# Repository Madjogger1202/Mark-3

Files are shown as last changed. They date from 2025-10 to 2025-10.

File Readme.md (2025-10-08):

# Mark 3 — Robot Dog Control Board

> High-current RP2350B-based controller board for quadruped robots.  
> Integrated **battery protection**, **PD charging**, **per-leg power domains**, and **radio/IMU** subsystem.  
> Designed for compact 4-legged robots with modular legs and high servo load.

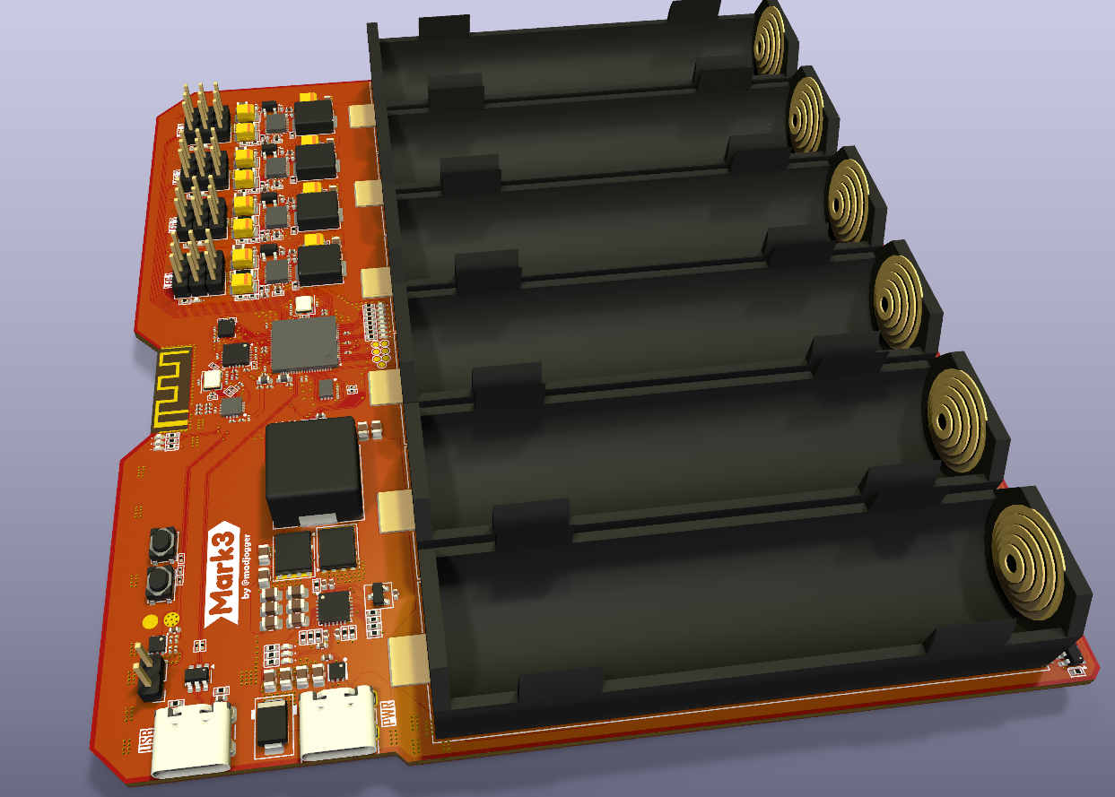
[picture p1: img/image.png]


---

## What’s on the board
- **Main MCU:** RP2350B (USB-programmable)
- **Power system:**
  - **6 × 18650** cells in **parallel** (on-board holders)
  - **Protection IC:** DW01 for undervoltage / overcurrent safety  
  - **USB Type-C PD** charging via **HUSB237-AA001-DN06R** (default 15 V profile, configurable)
  - **Battery charger:** BQ24610, up to **10 A charge current**
  - **Four TPS61088** boost converters — each provides **6 V / 10 A** per leg
  - Individual **enable lines** for each leg’s converter
  - **Current-sense** circuit per leg power rail
- **IMU:** LSM6DS3 (SPI interface)
- **Radio:** nRF24L01P (integrated 2.4 GHz transceiver)
- **LED indication:**
  - 8 × battery-level LEDs
  - 2 × status LEDs (power / charging / fault)
- **Two separate USB-C ports:**
  - **Programming** (direct to RP2350B)
  - **Charging** (PD trigger + BQ24610)
- **BOOT** button for UF2 flashing  
- All power and signal routing optimized for servo current spikes

---

## Power System Overview
| Function | Component | Voltage | Current | Notes |
|:--|:--|:--|:--|:--|
| PD Trigger | HUSB237-AA001-DN06R | 15 V (default) | up to 3 A | Configurable by resistors |
| Charger | BQ24610 | 15 V → Battery | up to 10 A | 1S6P Li-ion |
| Protection | DW01 | 1S | — | Undervoltage / overcurrent cutoff |
| Boost × 4 | TPS61088 | 6 V | 10 A each | One per leg |
| MCU & Logic | RP2350B + LDO | 3.3 V | — | Isolated domain |

> ⚠️ **Do not** connect external 5 V to the MCU port while PD charging.  
> Power and data paths are separate to prevent back-feed.

---

## Sensors & Interfaces
- **LSM6DS3 (SPI)** — motion sensing (accelerometer + gyroscope)  
- **nRF24L01P (SPI)** — wireless communication  
- Expansion headers for extra sensors (I²C / SPI / UART)  
- Servo outputs grouped per leg (3 per leg × 4 legs)

---

## Battery Section
- 6 × **18650 cells in parallel**
- **DW01** provides basic protection (no balancing)
- On-board holders for easy replacement
- **LED bar (8 segments)** for charge level indication

---
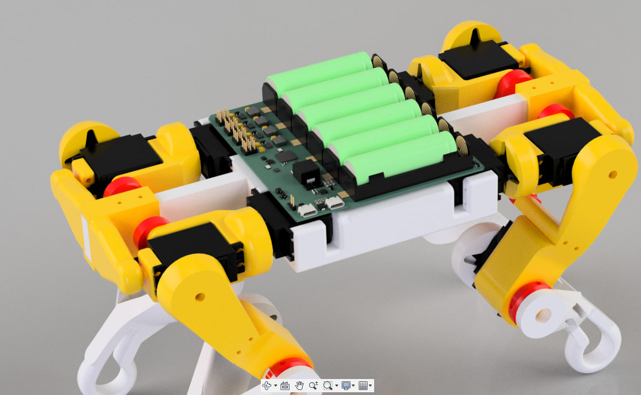
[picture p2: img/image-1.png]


## Quick Use
1. Insert 6× 18650 cells into holders.  
2. Connect USB-C **charging** port (PD trigger negotiates 15 V).  
3. Wait for charge LEDs to show full battery.  
4. Connect USB-C **programming** port to PC.  
5. Hold **BOOT** and power the board to enter UF2 mode.  
6. Flash firmware to RP2350B.  
7. Control each leg’s power domain and read current measurements as needed.

---

## Typical Applications
- Quadruped robots (up to 4 legs, 3 servos per leg)
- High-current servo testing rigs
- Portable motion control platforms
- Development base for RP2350 motion control firmware

---

## Notes
- Each leg’s 6 V converter (TPS61088) can be disabled via GPIO.  
- Charging and MCU USB ports are independent.  
- PD trigger default = 15 V (can be changed by resistor network).  
- Full pinout and schematics in `/docs/Mark3_schematic.pdf`.

---

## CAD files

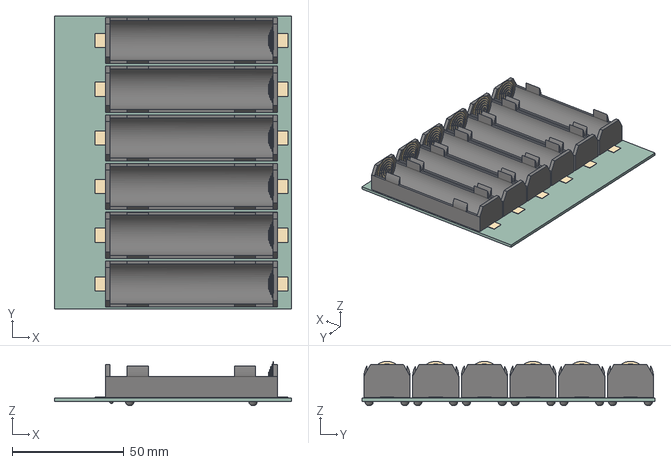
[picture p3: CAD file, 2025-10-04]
Mark-3.step
106.2 x 131.2 x 19.8 mm
BatteryHolder_Keystone_1042_1x18650 x 6
Mark-3_PCB

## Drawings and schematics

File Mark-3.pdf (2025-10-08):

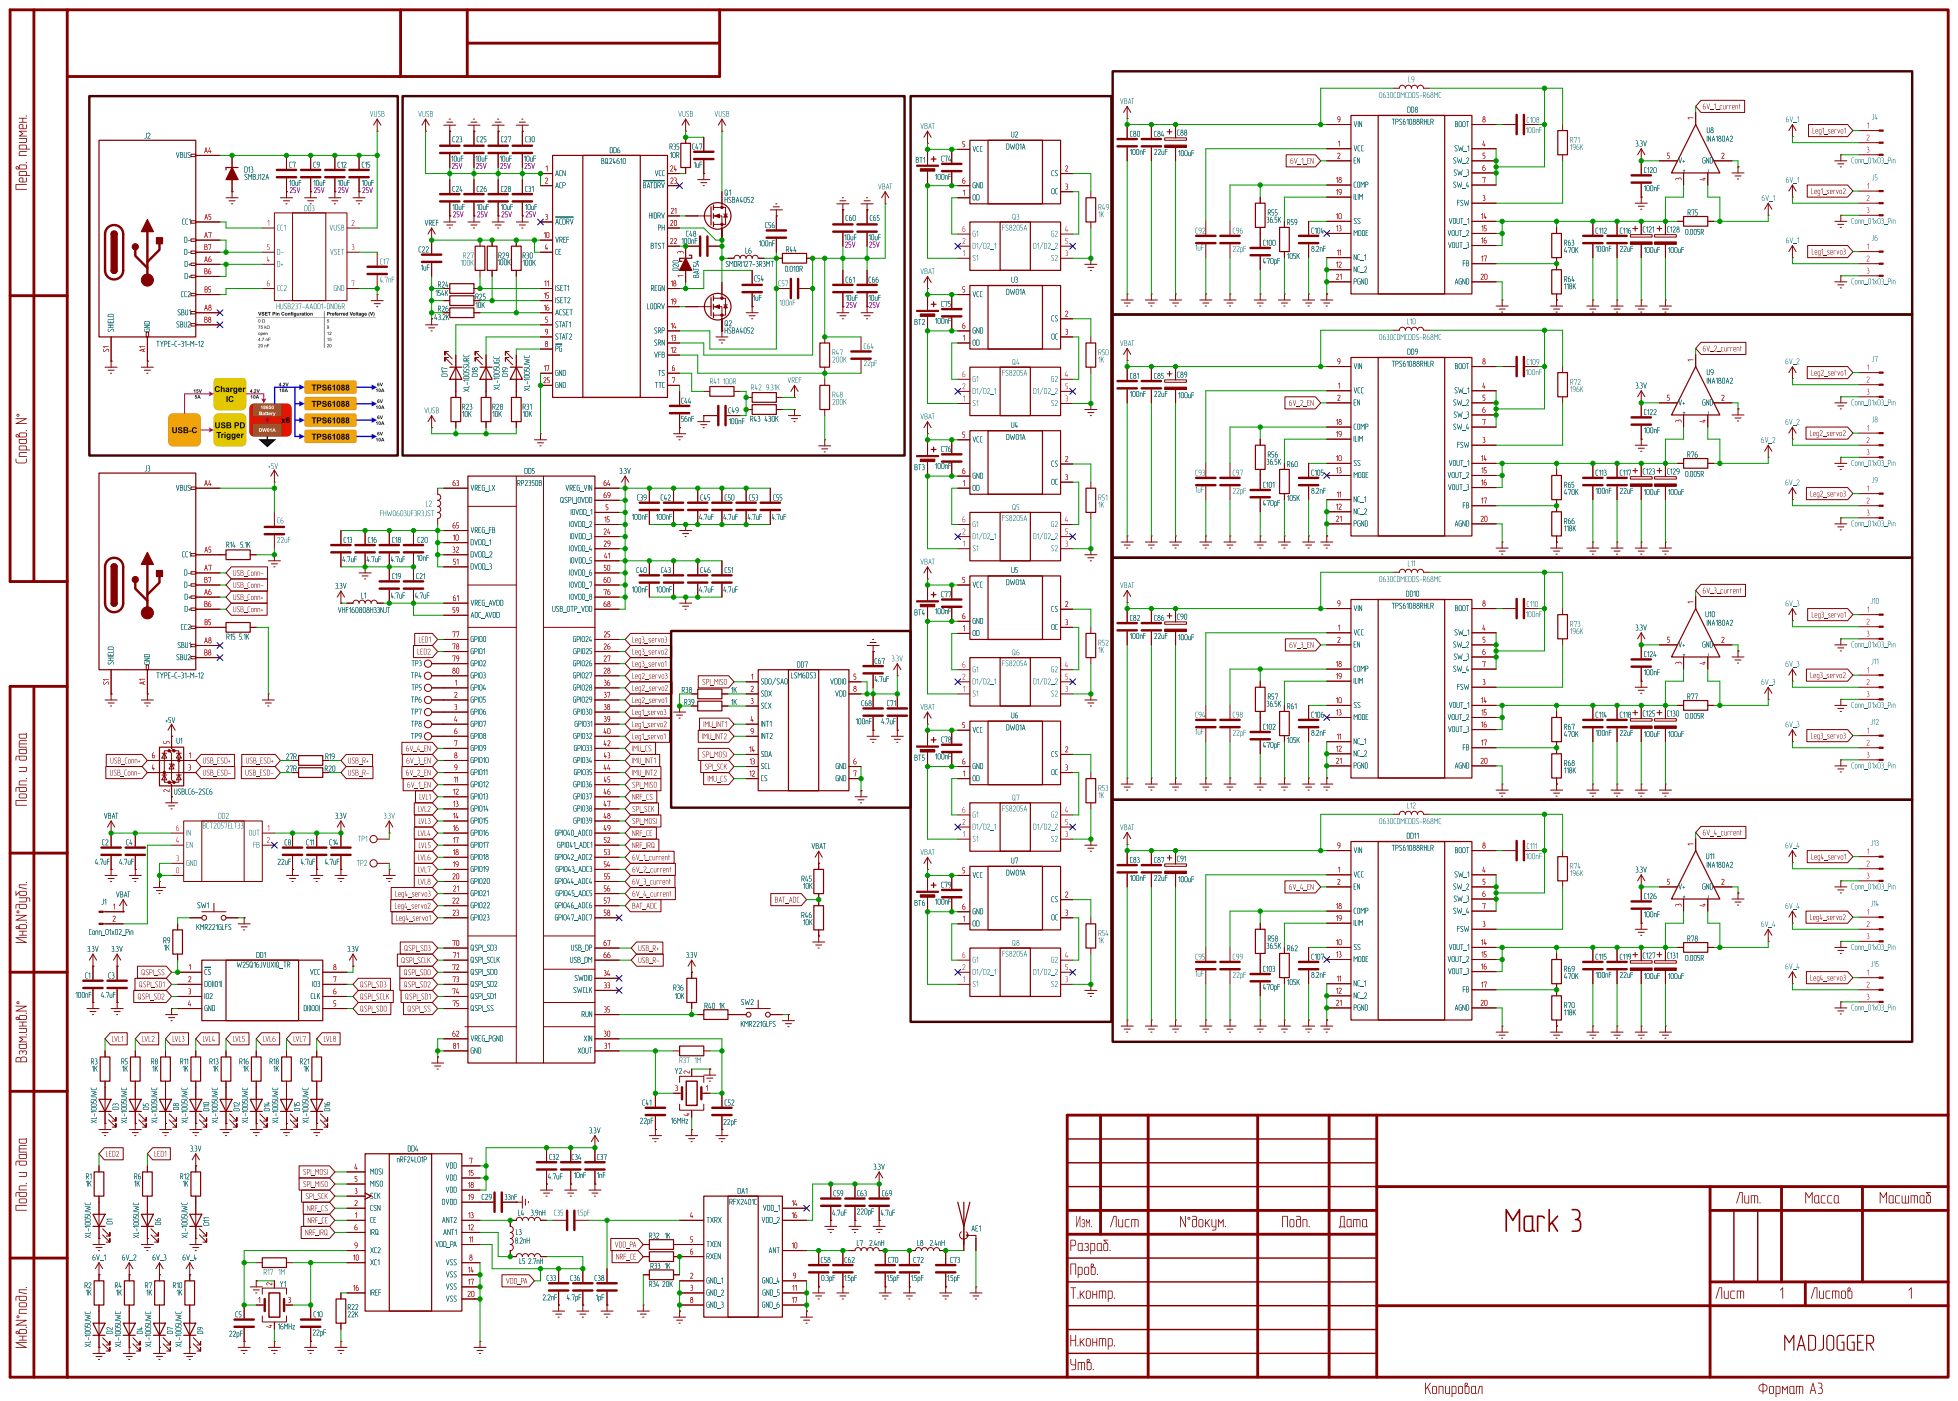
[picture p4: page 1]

VIN 9 VCC 1 EN 2 COMP 18

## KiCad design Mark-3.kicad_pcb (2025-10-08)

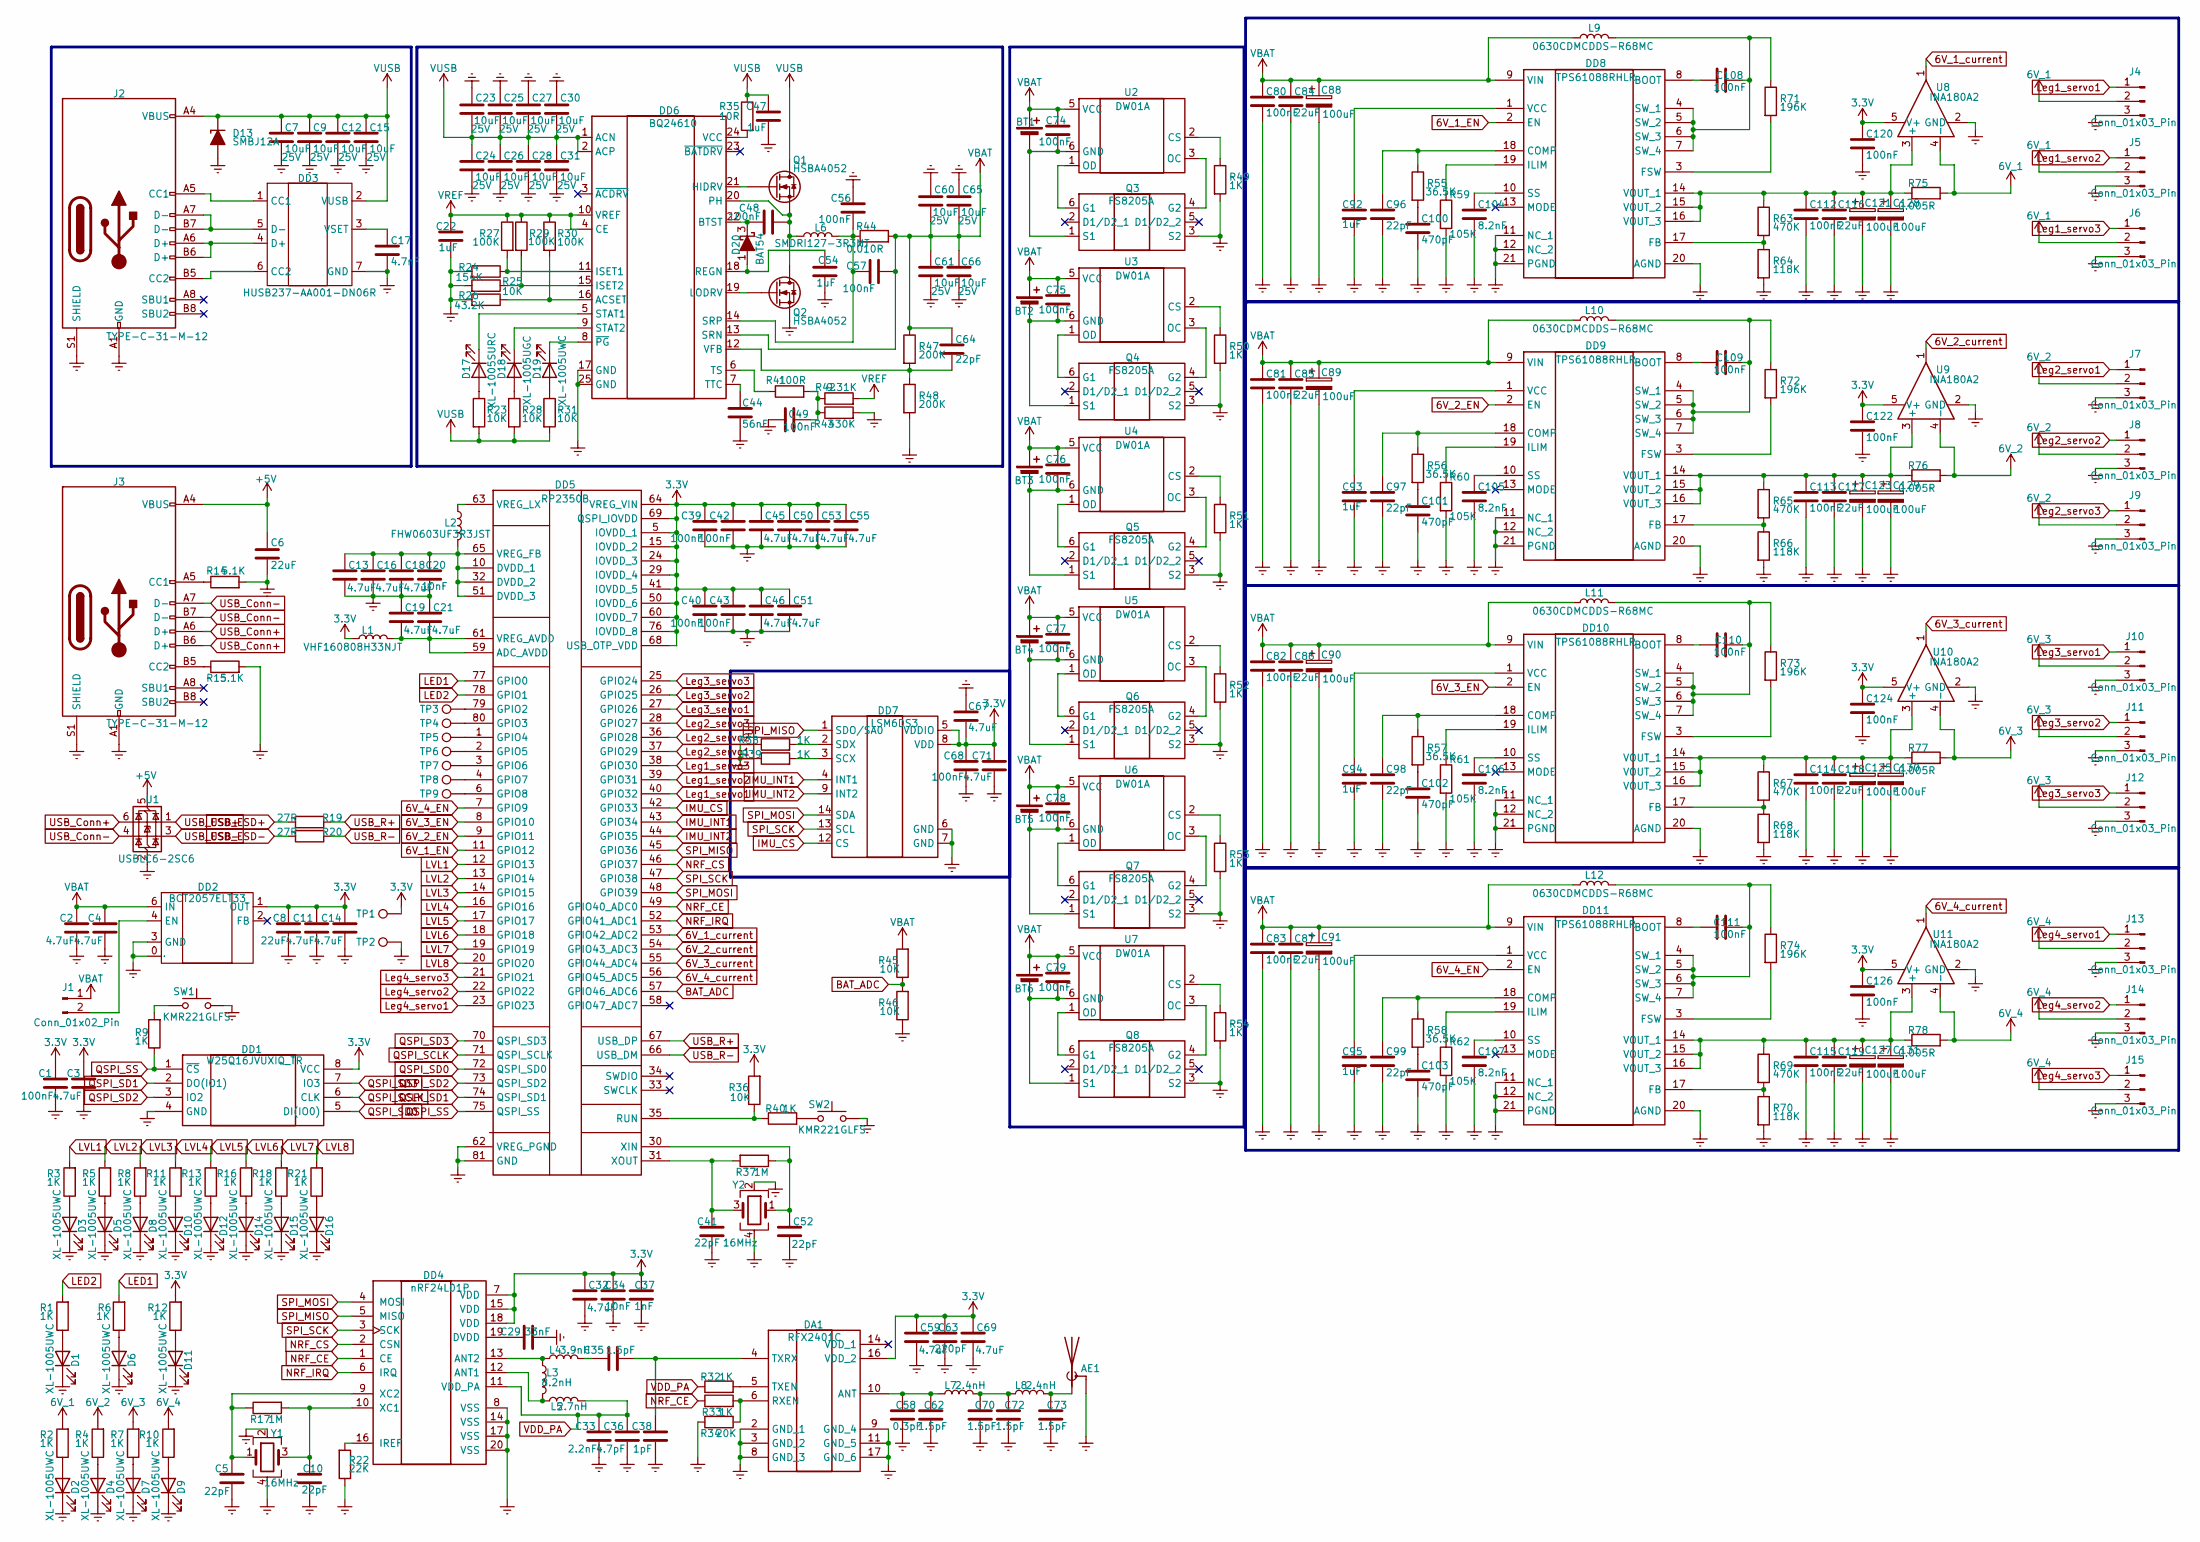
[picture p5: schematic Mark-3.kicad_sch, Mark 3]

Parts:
AE1: Antenna_Shield; Texas_SWRA117D_2.4GHz_Right
BT1, BT2, BT3, BT4, BT5, BT6: Battery_Cell; BatteryHolder_Keystone_1042_1x18650
C1, C39, C40, C42, C43, C68: 100nF; C_0201_0603Metric
C2, C3, C4, C11, C13, C14, C16, C18, C19, C21, C32, C45, C46, C50, C51, C53, C55, C59, C67, C69, C71: 4.7uF; C_0201_0603Metric
C5, C10, C41, C52: 22pF; C_0201_0603Metric
C6, C8: 22uF; C_0402_1005Metric
C7, C9, C12, C15, C23, C24, C25, C26, C27, C28, C30, C31, C60, C61, C65, C66: 10uF; C_0805_2012Metric; Voltage 25V; JLCPCB part C5674
C17: 4.7nF; C_0402_1005Metric; JLCPCB part C5674
C20, C34: 10nF; C_0201_0603Metric
C22, C47, C54, C92, C93, C94, C95: 1uF; C_0402_1005Metric; JLCPCB part C5674
C29: 33nF; C_0201_0603Metric
C33: 2.2nF; C_0201_0603Metric
C35, C62, C70, C72, C73: 1.5pF; C_0201_0603Metric
C36: 4.7pF; C_0201_0603Metric
C37: 1nF; C_0201_0603Metric
C38: 1pF; C_0201_0603Metric
C44: 56nF; C_0402_1005Metric; JLCPCB part C5674
C48, C49, C56, C57, C74, C75, C76, C77, C78, C79, C80, C81, C82, C83, C108, C109, C110, C111, C112, C113, C114, C115, C120, C122, C124, C126: 100nF; C_0402_1005Metric; JLCPCB part C5674
C58: 0.3pF; C_0201_0603Metric
C63: 220pF; C_0201_0603Metric
C64, C96, C97, C98, C99: 22pF; C_0402_1005Metric; JLCPCB part C5674
C84, C85, C86, C87, C116, C117, C118, C119: 22uF; C_0805_2012Metric; JLCPCB part C5674
C88, C89, C90, C91, C121, C123, C125, C127, C128, C129, C130, C131: 100uF; CP_EIA-3528-21_Kemet-B; JLCPCB part C140381
C100, C101, C102, C103: 470pF; C_0402_1005Metric; JLCPCB part C5674
C104, C105, C106, C107: 8.2nF; C_0402_1005Metric; JLCPCB part C5674
D1, D2, D3, D4, D5, D6, D7, D8, D9, D10, D11, D12, D14, D15, D16, D19: XL-1005UWC; LED_0402_1005Metric
D13: SMBJ12A; D_SMB
D17: XL-1005SURC; LED_0402_1005Metric
D18: XL-1005UGC; LED_0402_1005Metric
D20: BAT54; SOT-23
DA1: RFX2401C; Manufacturer_Part_Number RFX2401C; Mouser Part Number 477-RFX2401C
DD1: W25Q16JVUXIQ_TR; W25Q16JVUXIQ; Manufacturer_Part_Number W25Q16JVUXIQ TR; Mouser Part Number 454-W25Q16JVUXIQTR
DD2: BCT2057ELT33; BCT2057ELTAJ; Manufacturer Part BCT2057ELTAJ-TR; LCSC Part Name 1A, 低 dropout 线性稳压器
DD3: HUSB237-AA001-DN06R; Manufacturer Part HUSB237-AA001-DN06R; LCSC Part Name HUSB237-AA001-DN06R
DD4: nRF24L01P; QFN-20-1EP_4x4mm_P0.5mm_EP2.5x2.5mm
DD5: RP2350B; QFN40P1000X1000X90-81N-D; Manufacturer_Part_Number RP2350B
DD6: BQ24610; VQFN-24-1EP_4x4mm_P0.5mm_EP2.45x2.45mm
DD7: LSM6DS3; LGA-14_3x2.5mm_P0.5mm_LayoutBorder3x4y
DD8, DD9, DD10, DD11: TPS61088RHLR; Manufacturer_Part_Number TPS61088RHLR; Mouser Part Number 595-TPS61088RHLR
J1: Conn_01x02_Pin; PinHeader_1x02_P2.54mm_Vertical
J2: TYPE-C-31-M-12; USB_C_Receptacle_G-Switch_GT-USB-7010ASV
J3: TYPE-C-31-M-12; USB_C_Receptacle_GCT_USB4105-xx-A_16P_TopMnt_Horizontal
J4, J5, J6, J7, J8, J9, J10, J11, J12, J13, J14, J15: Conn_01x03_Pin; PinHeader_1x03_P2.54mm_Vertical
L1: VHF160808H33NJT; L_0603_1608Metric
L2: FHW0603UF3R3JST; L_0603_1608Metric
L3: 8.2nH; L_0201_0603Metric
L4: 3.9nH; L_0201_0603Metric
L5: 2.7nH; L_0201_0603Metric
L6: SMDRI127-3R3MT; L_SXN_SMDRI127
L7, L8: 2.4nH; L_0201_0603Metric
L9, L10, L11, L12: 0630CDMCDDS-R68MC; L_Sunlord_MWSA0603S
Q1, Q2: HSBA4052; PQFN-8-EP_6x5mm_P1.27mm_Generic
Q3, Q4, Q5, Q6, Q7, Q8: FS8205A; Manufacturer_Part_Number FS8205A
R1, R2, R3, R4, R5, R6, R7, R8, R10, R11, R12, R13, R16, R18, R21, R49, R50, R51, R52, R53, R54: 1K; R_0402_1005Metric
R9, R32, R33, R38, R39, R40: 1K; R_0201_0603Metric
R14, R15: 5.1K; R_0402_1005Metric
R17, R37: 1M; R_0201_0603Metric
R19, R20: 27R; R_0201_0603Metric
R22: 22K; R_0201_0603Metric
R23, R25, R28, R31: 10K; R_0402_1005Metric
R24: 154K; R_0402_1005Metric
R26: 43.2K; R_0402_1005Metric
R27, R29, R30: 100K; R_0402_1005Metric
R34: 20K; R_0201_0603Metric
R35: 10R; R_0402_1005Metric
R36, R45, R46: 10K; R_0201_0603Metric
R41: 100R; R_0402_1005Metric
R42: 9.31K; R_0402_1005Metric
R43: 430K; R_0402_1005Metric
R44: 0.010R; R_2512_6332Metric_Pad1.40x3.35mm
R47, R48: 200K; R_0402_1005Metric
R55, R56, R57, R58: 36.5K; R_0402_1005Metric
R59, R60, R61, R62: 105K; R_0402_1005Metric
R63, R65, R67, R69: 470K; R_0402_1005Metric
R64, R66, R68, R70: 118K; R_0402_1005Metric
R71, R72, R73, R74: 196K; R_0402_1005Metric
R75, R76, R77, R78: 0.005R; R_1206_3216Metric
SW1, SW2: KMR221GLFS; SW_SPST_PTS810
TP1, TP2, TP3, TP4, TP5, TP6, TP7, TP8, TP9: TestPoint; TestPoint_Pad_D1.0mm
U1: USBLC6-2SC6; SOT-23-6
U2, U3, U4, U5, U6, U7: DW01A; SOT-23-6
U8, U9, U10, U11: INA180A2; SOT-23-5
Y1, Y2: 16MHz; Crystal_SMD_3225-4Pin_3.2x2.5mm

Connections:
3.3V: C1.1, C3.1, C8.1, C11.1, C14.1, C32.1, C34.1, C37.1, C39.1, C40.1, C42.1, C43.1, C45.1, C46.1, C50.1, C51.1, C53.1, C55.1, C59.1, C63.1, C67.1, C68.1, C69.1, C71.1, C120.1, C122.1, C124.1, C126.1, DA1.16 (VDD_2), DD1.8 (VCC), DD2.1 (OUT), DD4.7 (VDD), DD4.15 (VDD), DD4.18 (VDD), DD5.5 (IOVDD_1), DD5.15 (IOVDD_2), DD5.24 (IOVDD_3), DD5.29 (IOVDD_4), DD5.41 (IOVDD_5), DD5.50 (IOVDD_6), DD5.60 (IOVDD_7), DD5.64 (VREG_VIN), DD5.68 (USB_OTP_VDD), DD5.69 (QSPI_IOVDD), DD5.76 (IOVDD_8), DD7.5 (VDDIO), DD7.8 (VDD), L1.1, R12.2, R36.2, TP1.1, U8.5 (V+), U9.5 (V+), U10.5 (V+), U11.5 (V+)
6V_1: J4.2, J5.2, J6.2, R2.2, R75.2, U8.4 (-)
6V_1_EN: DD5.11 (GPIO12), DD8.2 (EN)
6V_1_current: DD5.53 (GPIO42_ADC2), U8.1
6V_2: J7.2, J8.2, J9.2, R4.2, R76.2, U9.4 (-)
6V_2_EN: DD5.9 (GPIO11), DD9.2 (EN)
6V_2_current: DD5.54 (GPIO43_ADC3), U9.1
6V_3: J10.2, J11.2, J12.2, R7.2, R77.2, U10.4 (-)
6V_3_EN: DD5.8 (GPIO10), DD10.2 (EN)
6V_3_current: DD5.55 (GPIO44_ADC4), U10.1
6V_4: J13.2, J14.2, J15.2, R10.2, R78.2, U11.4 (-)
6V_4_EN: DD5.7 (GPIO9), DD11.2 (EN)
6V_4_current: DD5.56 (GPIO45_ADC5), U11.1
+5V: C6.1, J3.A4 (VBUS), J3.A9 (VBUS), J3.B4 (VBUS), J3.B9 (VBUS), U1.5 (VBUS)
BAT_ADC: DD5.57 (GPIO46_ADC6), R45.1, R46.2
Earth: AE1.2 (Shield), C1.2, C2.2, C3.2, C4.2, C5.2, C6.2, C7.2, C8.2, C9.2, C10.2, C11.2, C12.2, C13.2, C14.2, C15.2, C16.2, C17.2, C18.2, C19.1, C20.2, C21.1, C22.2, C23.2, C24.2, C25.2, C26.2, C27.2, C28.2, C29.2, C30.2, C31.2, C32.2, C33.2, C34.2, C36.2, C37.2, C38.2, C39.2, C40.2, C41.2, C42.2, C43.2, C44.2, C45.2, C46.2, C47.1, C49.1, C50.2, C51.2, C52.2, C53.2, C54.1, C55.2, C56.2, C58.2, C59.2, C60.2, C61.2, C62.2, C63.2, C65.2, C66.2, C67.2, C68.2, C69.2, C70.2, C71.2, C72.2, C73.2, C80.2, C81.2, C82.2, C83.2, C84.2, C85.2, C86.2, C87.2, C88.2, C89.2, C90.2, C91.2, C92.2, C93.2, C94.2, C95.2, C96.2, C97.2, C98.2, C99.2, C100.2, C101.2, C102.2, C103.2, C104.2, C105.2, C106.2, C107.2, C112.2, C113.2, C114.2, C115.2, C116.2, C117.2, C118.2, C119.2, C120.2, C121.2, C122.2, C123.2, C124.2, C125.2, C126.2, C127.2, C128.2, C129.2, C130.2, C131.2, D1.1 (K), D2.1 (K), D3.1 (K), D4.1 (K), D5.1 (K), D6.1 (K), D7.1 (K), D8.1 (K), D9.1 (K), D10.1 (K), D11.1 (K), D12.1 (K), D13.2 (A), D14.1 (K), D15.1 (K), D16.1 (K), DA1.2 (GND_1), DA1.3 (GND_2), DA1.8 (GND_3), DA1.9 (GND_4), DA1.11 (GND_5), DA1.17 (GND_6), DD1.4 (GND), DD2.0 (EP), DD2.3 (GND), DD3.7 (GND), DD4.8 (VSS), DD4.14 (VSS), DD4.17 (VSS), DD4.20 (VSS), DD4.21 (PAD), DD5.62 (VREG_PGND), DD5.81 (GND), DD6.17 (GND), DD6.25 (GND), DD7.6 (GND), DD7.7 (GND), DD8.11 (NC_1), DD8.12 (NC_2), DD8.20 (AGND), DD8.21 (PGND), DD9.11 (NC_1), DD9.12 (NC_2), DD9.20 (AGND), DD9.21 (PGND), DD10.11 (NC_1), DD10.12 (NC_2), DD10.20 (AGND), DD10.21 (PGND), DD11.11 (NC_1), DD11.12 (NC_2), DD11.20 (AGND), DD11.21 (PGND), J2.A1 (GND), J2.A12 (GND), J2.B1 (GND), J2.B12 (GND), J2.S1 (SHIELD), J3.A1 (GND), J3.A12 (GND), J3.B1 (GND), J3.B12 (GND), J3.S1 (SHIELD), J4.3, J5.3, J6.3, J7.3, J8.3, J9.3, J10.3, J11.3, J12.3, J13.3, J14.3, J15.3, Q2.1 (S), Q2.2 (S), Q2.3 (S), Q3.3 (S2), Q4.3 (S2), Q5.3 (S2), Q6.3 (S2), Q7.3 (S2), Q8.3 (S2), R14.2, R15.2, R22.1, R24.2, R25.2, R26.2, R34.2, R38.1, R39.1, R43.2, R46.1, R48.2, R49.2, R50.2, R51.2, R52.2, R53.2, R54.2, R59.2, R60.2, R61.2, R62.2, R64.2, R66.2, R68.2, R70.2, SW1.1, SW2.1, TP2.1, U1.2 (GND), U8.2 (GND), U9.2 (GND), U10.2 (GND), U11.2 (GND), Y1.2, Y1.4, Y2.2, Y2.4
IMU_CS: DD5.42 (GPIO33), DD7.12 (CS)
IMU_INT1: DD5.43 (GPIO34), DD7.4 (INT1)
IMU_INT2: DD5.44 (GPIO35), DD7.9 (INT2)
LED1: DD5.77 (GPIO0), R6.2
LED2: DD5.78 (GPIO1), R1.2
LVL1: DD5.12 (GPIO13), R3.2
LVL2: DD5.13 (GPIO14), R5.2
LVL3: DD5.14 (GPIO15), R8.2
LVL4: DD5.16 (GPIO16), R11.2
LVL5: DD5.17 (GPIO17), R13.2
LVL6: DD5.18 (GPIO18), R16.2
LVL7: DD5.19 (GPIO19), R18.2
LVL8: DD5.20 (GPIO20), R21.2
Leg1_servo1: DD5.40 (GPIO32), J4.1
Leg1_servo2: DD5.39 (GPIO31), J5.1
Leg1_servo3: DD5.38 (GPIO30), J6.1
Leg2_servo1: DD5.37 (GPIO29), J7.1
Leg2_servo2: DD5.36 (GPIO28), J8.1
Leg2_servo3: DD5.28 (GPIO27), J9.1
Leg3_servo1: DD5.27 (GPIO26), J10.1
Leg3_servo2: DD5.26 (GPIO25), J11.1
Leg3_servo3: DD5.25 (GPIO24), J12.1
Leg4_servo1: DD5.23 (GPIO23), J13.1
Leg4_servo2: DD5.22 (GPIO22), J14.1
Leg4_servo3: DD5.21 (GPIO21), J15.1
NRF_CE: DD4.1 (CE), DD5.49 (GPIO40_ADC0), R33.1
NRF_CS: DD4.2 (CSN), DD5.46 (GPIO37)
NRF_IRQ: DD4.6 (IRQ), DD5.52 (GPIO41_ADC1)
unnamed: AE1.1 (A), C73.1, L8.2
unnamed: BT1.2 (-), C74.2, Q3.1 (S1), U2.6 (GND)
unnamed: BT2.2 (-), C75.2, Q4.1 (S1), U3.6 (GND)
unnamed: BT3.2 (-), C76.2, Q5.1 (S1), U4.6 (GND)
unnamed: BT4.2 (-), C77.2, Q6.1 (S1), U5.6 (GND)
unnamed: BT5.2 (-), C78.2, Q7.1 (S1), U6.6 (GND)
unnamed: BT6.2 (-), C79.2, Q8.1 (S1), U7.6 (GND)
unnamed: C35.1, L4.2
unnamed: C49.2, R41.2, R42.1, R43.1
unnamed: C70.1, C72.1, L7.2, L8.1
unnamed: C100.1, R55.2
unnamed: C101.1, R56.2
unnamed: C102.1, R57.2
unnamed: C103.1, R58.2
unnamed: D1.2 (A), R1.1
unnamed: D2.2 (A), R2.1
unnamed: D3.2 (A), R3.1
unnamed: D4.2 (A), R4.1
unnamed: D5.2 (A), R5.1
unnamed: D6.2 (A), R6.1
unnamed: D7.2 (A), R7.1
unnamed: D8.2 (A), R8.1
unnamed: D9.2 (A), R10.1
unnamed: D10.2 (A), R11.1
unnamed: D11.2 (A), R12.1
unnamed: D12.2 (A), R13.1
unnamed: D14.2 (A), R16.1
unnamed: D15.2 (A), R18.1
unnamed: D16.2 (A), R21.1
unnamed: D17.2 (A), R23.1
unnamed: D17.1 (K), DD6.5 (STAT1)
unnamed: D18.2 (A), R28.1
unnamed: D18.1 (K), DD6.9 (STAT2)
unnamed: D19.2 (A), R31.1
unnamed: D19.1 (K), DD6.8 (~PG)
unnamed: C54.2, D20.1 (A), DD6.18 (REGN)
unnamed: C48.1, D20.3 (K), DD6.22 (BTST)
unnamed: C58.1, C62.1, DA1.10 (ANT), L7.1
unnamed: DA1.6 (RXEN), R33.2, R34.1
unnamed: DA1.5 (TXEN), R32.2
unnamed: C35.2, C38.1, DA1.4 (TXRX)
unnamed: DD2.4 (EN), J1.2
unnamed: DD3.1 (CC1), J2.A5 (CC1)
unnamed: DD3.6 (CC2), J2.B5 (CC2)
unnamed: DD3.4 (D+), J2.A6 (D+), J2.B6 (D+)
unnamed: DD3.5 (D-), J2.A7 (D-), J2.B7 (D-)
unnamed: C17.1, DD3.3 (VSET)
unnamed: DD4.12 (ANT1), L3.2, L5.1
unnamed: DD4.13 (ANT2), L3.1, L4.1
unnamed: C29.1, DD4.19 (DVDD)
unnamed: DD4.16 (IREF), R22.2
unnamed: C10.1, DD4.10 (XC1), R17.2, Y1.3
unnamed: C5.1, DD4.9 (XC2), R17.1, Y1.1
unnamed: C19.2, C21.2, DD5.59 (ADC_AVDD), DD5.61 (VREG_AVDD), L1.2
unnamed: C13.1, C16.1, C18.1, C20.1, DD5.10 (DVDD_1), DD5.32 (DVDD_2), DD5.51 (DVDD_3), DD5.65 (VREG_FB), L2.2
unnamed: DD5.79 (GPIO2), TP3.1
unnamed: DD5.80 (GPIO3), TP4.1
unnamed: DD5.1 (GPIO4), TP5.1
unnamed: DD5.2 (GPIO5), TP6.1
unnamed: DD5.3 (GPIO6), TP7.1
unnamed: DD5.4 (GPIO7), TP8.1
unnamed: DD5.6 (GPIO8), TP9.1
unnamed: DD5.35 (RUN), R36.1, R40.1
unnamed: DD5.63 (VREG_LX), L2.1
unnamed: C52.1, DD5.30 (XIN), R37.1, Y2.1
unnamed: C41.1, DD5.31 (XOUT), R37.2, Y2.3
unnamed: DD6.16 (ACSET), R26.1, R30.2
unnamed: DD6.21 (HIDRV), Q1.4 (G)
unnamed: DD6.11 (ISET1), R24.1, R27.2
unnamed: DD6.15 (ISET2), R25.1, R29.2
unnamed: DD6.19 (LODRV), Q2.4 (G)
unnamed: C56.1, C57.1, DD6.14 (SRP), L6.2, R44.1
unnamed: DD6.6 (TS), R41.1
unnamed: C44.1, DD6.7 (TTC)
unnamed: DD6.24 (VCC), R35.2
unnamed: C64.2, DD6.12 (VFB), R47.2, R48.1
unnamed: DD7.3 (SCX), R39.2
unnamed: DD7.2 (SDX), R38.2
unnamed: C108.1, DD8.8 (BOOT)
unnamed: C96.1, DD8.18 (COMP), R55.1
unnamed: DD8.17 (FB), R63.2, R64.1
unnamed: DD8.3 (FSW), R71.2
unnamed: DD8.19 (ILIM), R59.1
unnamed: C104.1, DD8.10 (SS)
unnamed: C108.2, DD8.4 (SW_1), DD8.5 (SW_2), DD8.6 (SW_3), DD8.7 (SW_4), L9.2, R71.1
unnamed: C92.1, DD8.1 (VCC)
unnamed: C112.1, C116.1, C121.1, C128.1, DD8.14 (VOUT_1), DD8.15 (VOUT_2), DD8.16 (VOUT_3), R63.1, R75.1, U8.3 (+)
unnamed: C109.1, DD9.8 (BOOT)
unnamed: C97.1, DD9.18 (COMP), R56.1
unnamed: DD9.17 (FB), R65.2, R66.1
unnamed: DD9.3 (FSW), R72.2
unnamed: DD9.19 (ILIM), R60.1
unnamed: C105.1, DD9.10 (SS)
unnamed: C109.2, DD9.4 (SW_1), DD9.5 (SW_2), DD9.6 (SW_3), DD9.7 (SW_4), L10.2, R72.1
unnamed: C93.1, DD9.1 (VCC)
unnamed: C113.1, C117.1, C123.1, C129.1, DD9.14 (VOUT_1), DD9.15 (VOUT_2), DD9.16 (VOUT_3), R65.1, R76.1, U9.3 (+)
unnamed: C110.1, DD10.8 (BOOT)
unnamed: C98.1, DD10.18 (COMP), R57.1
unnamed: DD10.17 (FB), R67.2, R68.1
unnamed: DD10.3 (FSW), R73.2
unnamed: DD10.19 (ILIM), R61.1
unnamed: C106.1, DD10.10 (SS)
unnamed: C110.2, DD10.4 (SW_1), DD10.5 (SW_2), DD10.6 (SW_3), DD10.7 (SW_4), L11.2, R73.1
unnamed: C94.1, DD10.1 (VCC)
unnamed: C114.1, C118.1, C125.1, C130.1, DD10.14 (VOUT_1), DD10.15 (VOUT_2), DD10.16 (VOUT_3), R67.1, R77.1, U10.3 (+)
unnamed: C111.1, DD11.8 (BOOT)
unnamed: C99.1, DD11.18 (COMP), R58.1
unnamed: DD11.17 (FB), R69.2, R70.1
unnamed: DD11.3 (FSW), R74.2
unnamed: DD11.19 (ILIM), R62.1
unnamed: C107.1, DD11.10 (SS)
unnamed: C111.2, DD11.4 (SW_1), DD11.5 (SW_2), DD11.6 (SW_3), DD11.7 (SW_4), L12.2, R74.1
unnamed: C95.1, DD11.1 (VCC)
unnamed: C115.1, C119.1, C127.1, C131.1, DD11.14 (VOUT_1), DD11.15 (VOUT_2), DD11.16 (VOUT_3), R69.1, R78.1, U11.3 (+)
unnamed: J3.A5 (CC1), R14.1
unnamed: J3.B5 (CC2), R15.1
unnamed: Q3.6 (G1), U2.1 (OD)
unnamed: Q3.4 (G2), U2.3 (OC)
unnamed: Q4.6 (G1), U3.1 (OD)
unnamed: Q4.4 (G2), U3.3 (OC)
unnamed: Q5.6 (G1), U4.1 (OD)
unnamed: Q5.4 (G2), U4.3 (OC)
unnamed: Q6.6 (G1), U5.1 (OD)
unnamed: Q6.4 (G2), U5.3 (OC)
unnamed: Q7.6 (G1), U6.1 (OD)
unnamed: Q7.4 (G2), U6.3 (OC)
unnamed: Q8.6 (G1), U7.1 (OD)
unnamed: Q8.4 (G2), U7.3 (OC)
unnamed: R9.2, SW1.2
unnamed: R40.2, SW2.2
unnamed: R49.1, U2.2 (CS)
unnamed: R50.1, U3.2 (CS)
unnamed: R51.1, U4.2 (CS)
unnamed: R52.1, U5.2 (CS)
unnamed: R53.1, U6.2 (CS)
unnamed: R54.1, U7.2 (CS)
QSPI_SCLK: DD1.6 (CLK), DD5.71 (QSPI_SCLK)
QSPI_SD0: DD1.5 (DI(IO0)), DD5.72 (QSPI_SD0)
QSPI_SD1: DD1.2 (DO(IO1)), DD5.74 (QSPI_SD1)
QSPI_SD2: DD1.3 (IO2), DD5.73 (QSPI_SD2)
QSPI_SD3: DD1.7 (IO3), DD5.70 (QSPI_SD3)
QSPI_SS: DD1.1 (~CS), DD5.75 (QSPI_SS), R9.1
SPI_MISO: DD4.5 (MISO), DD5.45 (GPIO36), DD7.1 (SDO/SA0)
SPI_MOSI: DD4.4 (MOSI), DD5.48 (GPIO39), DD7.14 (SDA)
SPI_SCK: DD4.3 (SCK), DD5.47 (GPIO38), DD7.13 (SCL)
USB_Conn+: J3.A6 (D+), J3.B6 (D+), U1.6 (I/O1)
USB_Conn-: J3.A7 (D-), J3.B7 (D-), U1.4 (I/O2)
USB_ESD+: R19.2, U1.1 (I/O1)
USB_ESD-: R20.2, U1.3 (I/O2)
USB_R+: DD5.67 (USB_DP), R19.1
USB_R-: DD5.66 (USB_DM), R20.1
VBAT: BT1.1 (+), BT2.1 (+), BT3.1 (+), BT4.1 (+), BT5.1 (+), BT6.1 (+), C2.1, C4.1, C57.2, C60.1, C61.1, C64.1, C65.1, C66.1, C74.1, C75.1, C76.1, C77.1, C78.1, C79.1, C80.1, C81.1, C82.1, C83.1, C84.1, C85.1, C86.1, C87.1, C88.1, C89.1, C90.1, C91.1, DD2.6 (IN), DD6.13 (SRN), DD8.9 (VIN), DD9.9 (VIN), DD10.9 (VIN), DD11.9 (VIN), J1.1, L9.1, L10.1, L11.1, L12.1, R44.2, R45.2, R47.1, U2.5 (VCC), U3.5 (VCC), U4.5 (VCC), U5.5 (VCC), U6.5 (VCC), U7.5 (VCC)
VDD_PA: C33.1, C36.1, DD4.11 (VDD_PA), L5.2, R32.1
VREF: C22.1, DD6.4 (CE), DD6.10 (VREF), R27.1, R29.1, R30.1, R42.2
VUSB: C7.1, C9.1, C12.1, C15.1, C23.1, C24.1, C25.1, C26.1, C27.1, C28.1, C30.1, C31.1, C47.2, D13.1 (K), DD3.2 (VUSB), DD6.1 (ACN), DD6.2 (ACP), J2.A4 (VBUS), J2.A9 (VBUS), J2.B4 (VBUS), J2.B9 (VBUS), Q1.5 (D), R23.2, R28.2, R31.2, R35.1

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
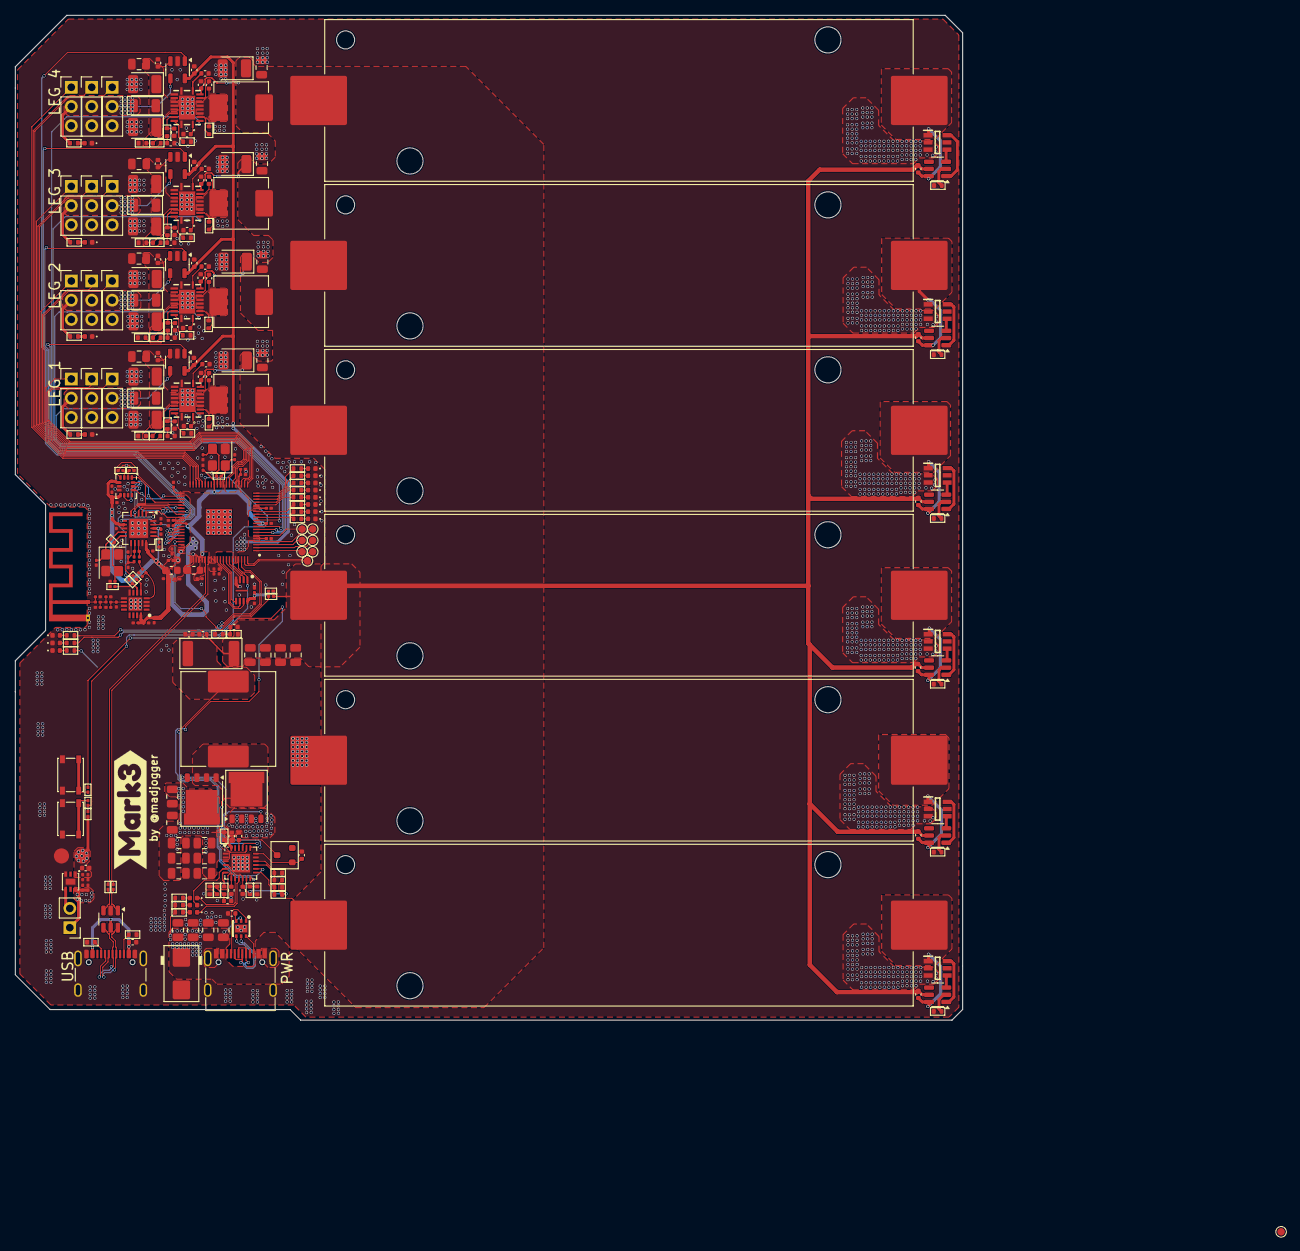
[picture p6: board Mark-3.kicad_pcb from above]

Board: 2 copper layers, 125.2 x 132.8 mm, 309 parts (0 on the bottom side), 200 nets.

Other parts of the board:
TP8#2: TestPoint; TestPoint_Pad_D1.0mm
kibuzzard-68E68F97: G***; kibuzzard-68E68F97

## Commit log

2025-09-30 initial commit, work in progress
    [Mark-3.kicad_pcb, Mark-3.kicad_sch]
2025-10-02 DC-DC and battery protection circuit done, partly done charger module
    [Mark-3.kicad_sch]
2025-10-04 Partly done placement, moving forward to GPIO assigment with placement spec
    [Mark-3.kicad_pcb, Mark-3.kicad_sch, Mark-3.step]
2025-10-04 UPD schematics
2025-10-05 schematics update
2025-10-08 rev0 ready
    [Mark-3.kicad_pcb, Mark-3.kicad_sch]
